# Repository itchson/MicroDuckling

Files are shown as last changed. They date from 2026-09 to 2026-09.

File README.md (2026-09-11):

<p align="center">
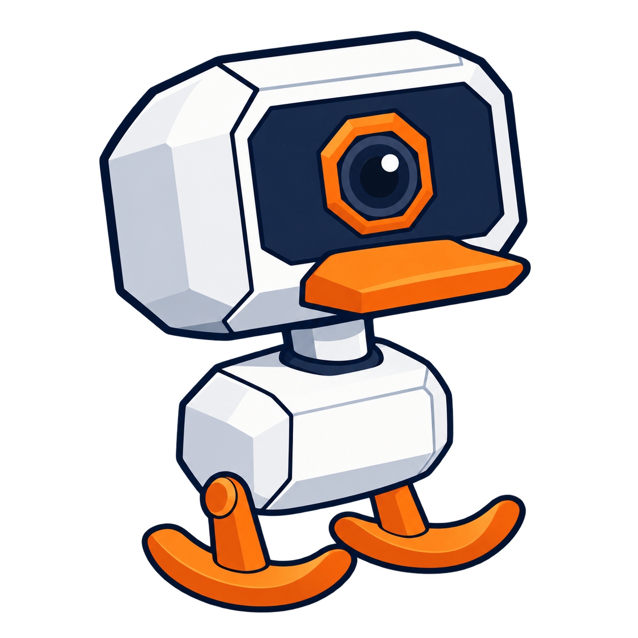
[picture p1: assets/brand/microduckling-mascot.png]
MicroDuckling: a white robot duck with a single camera and orange curved feet
  
</p>

<h1 align="center">MicroDuckling</h1>
<p align="center">A little robot to print, build, learn from and improve together.</p>
<p align="center">
  
  
  
</p>

MicroDuckling is an independent hobby robot project inspired by [Microduck from Pollen Robotics / Hugging Face](https://pollen-robotics.com/microduck/). The goal is a **small, affordable robot that people can build with printed parts and accessible electronics**, then make better as a community.

The design pairs a big faceted head and a small white body with smooth orange rocker feet. Four MG90S servos move the left leg, right leg, neck and mouth. A separate upper-mouth base mounts beneath the front of the head hood, while the lower jaw opens. The face panel is independent of the upper mouth. Printed-part assembly connections use M2 fasteners. Integrated sockets in the legs, neck carrier and jaw engage the servo output splines directly; their provisional profile still needs qualification against the actual servo batch. A local browser experiment runs rigid-body physics, searches gait patterns and approaches camera-visible targets. **NVIDIA Isaac Sim / Isaac Lab** and useful movements on real hardware remain development goals.

**This is an early CAD prototype, not a proven walking kit.** Contributions that uncover a fit problem, reduce cost, simplify assembly or improve the simulation are part of the project’s purpose.

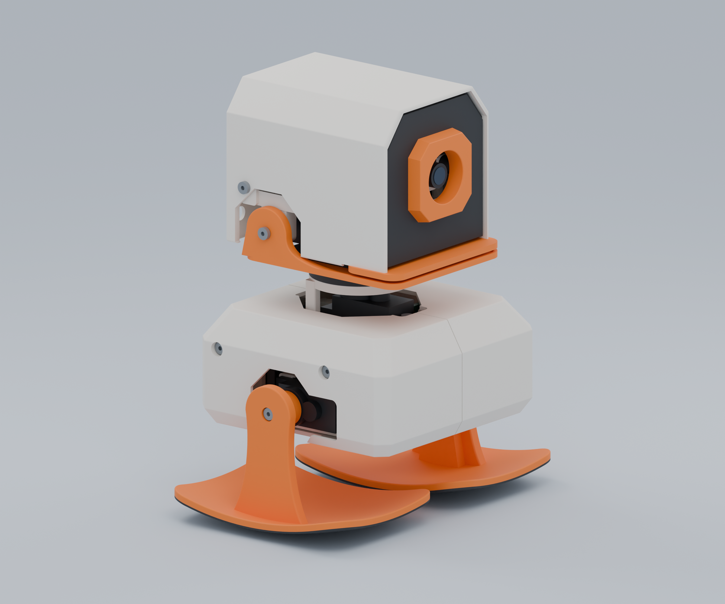
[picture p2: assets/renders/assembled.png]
R08 mechanical design and electronics visuals, assembled three-quarter view

<p align="center"><em>R08 mechanical design with separately licensed electronics visuals. The mascot is an illustration; neither image is a photograph of a working robot.</em></p>

## Where it stands

| Area | Current state |
| --- | --- |
| Mechanical design | R08: 15 robot print parts, two fit coupons, shell-mounted upper-mouth base and integrated direct servo sockets |
| Size and mass | About 136 mm tall; 250 g estimated complete mass, not measured |
| CAD checks | Printable mesh checks and sampled clearance reviews completed on the source design |
| Physical assembly | Not yet verified with printed parts and the specified hardware |
| Electronics and firmware | Four direct ESP32-CAM PWM signals and one shared 5 V regulator; I/O source and wiring supplied, hardware application/testing unfinished |
| Walking | Browser contact-model experiments; physical walking, servo temperature and traction need bench tests |
| Simulation | Physical gait search and geometric-camera approach checks tied to each asset revision; Isaac Lab scaffold remains unexecuted |
| Affordability | Proposed build with budget regulator: about A$100–110 including battery and print material; alternative mounts and power testing required |

Australian prices checked on 11 September 2026. The budget alternative uses different boards from the current CAD reference and excludes shipping, charger and tools. See [parts and costs](docs/parts-research.md), the [BOM](docs/bom.md) and the [engineering review](docs/engineering-review.md).

## Start exploring

- **Inspect the design:** open [the mechanical FreeCAD model](cad/MicroDuckling_R05_mechanical.FCStd) or [the printed-part STEP](cad/MicroDuckling_R05_printed.step).
- **Browse print files:** [STL](cad/stl/) and [3MF](cad/3mf/). Start with the clearance and spline fit coupons and the [hardware measurement checklist](docs/hardware-measurements.md); a full print is not yet qualified.
- **Understand the assembly:** read the [assembly review](docs/design-and-assembly.md) and [R08 changes](docs/r08-upper-mouth-design.md).
- **Work on simulation:** start with the [simulation guide](docs/simulation.md) and [roadmap](ROADMAP.md).

The viewer includes **82 assembly records plus two fit coupons**: 80 mechanical records and two separately supplied component visuals. R08 retains direct servo sockets without horn arms; its upper-mouth base mounts to the head shell using M2 fasteners. The IMU adapts an Adafruit PCB under CC BY-SA 3.0; the shared regulator is an original approximation. The PCA9685 and second regulator were removed. Native mechanical CAD and printed-part STEP stay separate, while mass accounts for the complete intended robot. See [license scope](docs/licensing.md) and [direct wiring](docs/electronics.md).

### Run the CAD viewer locally

Install Node.js 22.18 or newer (Node 24 is used in CI), then:

```sh
git clone https://github.com/itchson/MicroDuckling.git
cd MicroDuckling/viewer
npm ci
npm run dev
```

Open the local address printed in the terminal, normally `http://127.0.0.1:5192`. Orbit the model, select and isolate parts, open the exploded view, inspect the inside and pose the four joints. Separate browser physics controls run a gravity/contact experiment, search bounded gait parameters and test camera control using a synthetic 96 × 72 image. Joint sliders alone are a pose preview; none of these controls command hardware. FreeCAD is not required to use the viewer. See the [simulation guide](docs/simulation.md) for test coverage and the measured simulation criteria and remaining hardware limitations.

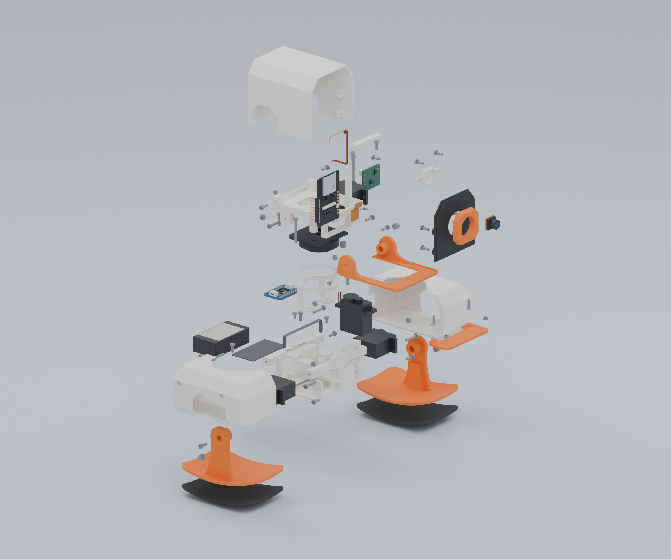
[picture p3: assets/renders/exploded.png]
Exploded view of MicroDuckling with the ESP32-CAM, IMU and single regulator


### Develop the design

The [developer guide](docs/development.md) covers the CAD toolchain, optional supplier reference downloads and checks. Parametric Python source lives in [src](src/); the native public model contains editable solids. The source is the place to change design parameters and regenerate geometry.

```sh
python -m pip install -r requirements-dev.txt
python scripts/validate_repository.py
python -m unittest discover -s simulation/tests
cd viewer
npm ci
npm test
npm run build
```

## Help a little duckling grow

You do not need to solve the whole robot to contribute. A measured servo spline, a clearly photographed fit failure, a cheaper power option, a better assembly step or a reproducible simulation result can all help.

Read [CONTRIBUTING](CONTRIBUTING.md), browse the [roadmap](ROADMAP.md), or [open an issue](https://github.com/itchson/MicroDuckling/issues/new/choose). Please include what you actually tested and distinguish measured results from estimates. The [conduct](CODE_OF_CONDUCT.md) and [governance](GOVERNANCE.md) documents explain how we work together.

## License and inspiration

Original MicroDuckling source, documentation, mechanical exports and independently authored regulator visuals use [Apache-2.0](LICENSE). The Adafruit IMU adaptation and electronics-inclusive presentation renders/thumbnails use **CC BY-SA 3.0**, with credit to Limor Fried/Ladyada for Adafruit Industries and MicroDuckling contributors. Notices for the former PCA9685 adaptation remain for historical releases. Adapted shadcn UI files retain MIT notices. See [license scope](docs/licensing.md) and [third-party notices](THIRD_PARTY_NOTICES.md) before redistributing assets.

MicroDuckling is an independent fan project, with its own design and identity. It is not an official Microduck model, a scaled copy of the official CAD, or affiliated with or endorsed by Hugging Face, Pollen Robotics or NVIDIA. Their names identify inspiration and intended tooling. The original mascot was made with OpenAI image generation; its [prompt and provenance](assets/brand/PROVENANCE.md) are included.

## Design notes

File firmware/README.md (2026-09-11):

# Direct servo I/O component

This ESP-IDF component implements the [direct-GPIO wiring plan](../docs/electronics.md): four servo signals, an OV2640 camera configuration, and a separate IMU I²C bus. It is a bring-up component, not a complete robot application or a tested hardware walking policy.

Use classic ESP32, ESP-IDF 5.4/5.5, and pinned `espressif/esp32-camera` 2.1.6. Add `components/microduckling_io` to an ESP-IDF application's components and merge `sdkconfig.defaults`, then inspect the resulting menuconfig. There is no top-level `app_main` here. GPIO16/17 stay assigned to PSRAM; microSD is unused. The component deliberately refuses a build with the wrong chip, camera I²C bus, or UART console settings.

The four servo functions require explicit measured calibration; no generic microseconds-to-angle mapping is represented as valid for the assembled robot. `md_servos_init(calibration)` starts at zero duty, with no servo pulses. `md_servos_write(angles)` accepts radians in left hip, right hip, neck, jaw order and rejects angles outside ±12°, ±12°, ±45°, and 0..12°. The 500–2500 µs outer software envelope only rejects obviously invalid calibration data; it is not an assertion that a particular servo or mechanism permits that entire range. Use smaller measured pulse bounds.

Call the servo API from one control task. Call `md_servos_stop()` on a control timeout or fault and provide a physical servo-power disconnect. LEDC can continue its last pulse train while the application is stuck; stopping PWM also does not guarantee that every servo batch releases torque. Fault detection, watchdog policy, power switching, sensing, networking, and walking control remain application work.

Duty writes use `ledc_set_duty()` followed by `ledc_update_duty()`, with both errors checked. This single-task component does not install the LEDC fade service required by ESP-IDF's combined `ledc_set_duty_and_update()` helper. Other tasks must not change its channels or start a fade on them. The [ESP-IDF 5.5.2 implementation](https://github.com/espressif/esp-idf/blob/v5.5.2/components/esp_driver_ledc/src/ledc.c) defines that service requirement.

Initialize the camera with the value from `md_camera_config()`. `md_imu_bus_init(&bus)` creates the new-driver I²C1 bus on SDA3/SCL1 with external 3.3 V pull-ups; attach the selected sensor driver at 100 kHz initially. Camera SCCB uses I²C0. Do not install the legacy I²C driver alongside the new driver. UART programming requires opening both IMU signal links; runtime UART logs are disabled.

Run `sh firmware/tests/run-host.sh` from the repository root on Linux to check pin/timer separation, command bounds, pulse conversion, and error handling. The [host-test instructions](tests/README.md) also cover Windows through WSL and explain the original test doubles. No ESP-IDF target build or board test has been completed in this environment, which has no installed ESP-IDF toolchain. Scope the 50 Hz pulses and 20 MHz camera clock together, verify camera/PSRAM/IMU operation, and qualify reset and loaded power behavior before connecting installed servo horns.

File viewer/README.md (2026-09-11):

# Local CAD viewer and physics experiment

Run from this directory with Node.js 22.18+ (CI uses Node 24):

```sh
npm ci
npm run dev
```

The terminal prints the local address, normally `http://127.0.0.1:5192`. A WebGL-capable browser is required. FreeCAD, supplier downloads, accounts and cloud services are not required.

The viewer combines 87 mechanical assembly records with four separately licensed electronics visuals; two fit coupons are also available. The parts hierarchy starts collapsed. Orbit, isolation, inside view, an assembly/explosion slider and joint sliders inspect the design. At 100% explosion, conservative mesh bounds have a gap between every component; intermediate positions are an illustration, not a collision-free removal path.

The Simulation tab runs Rapier rigid-body physics and a seeded cross-entropy search over bounded gait parameters. Its synthetic head camera renders 96 × 72 pixels, detects a magenta target and supplies only bearing/area observations to a controller. Camera learning tests bounded controller settings against visibility, centering, apparent-area growth and fall scores. It does not recognize arbitrary objects or connect to an ESP32 camera. Body travel comes from simulation, and none of these controls command hardware. See the [simulation guide](../docs/simulation.md) for assumptions and measured limitations.

`npm run prepare:cad` stages explicitly permitted CAD, component, asset and documentation files into ignored `public/`. Development, tests and builds run this step automatically. Full local engineering builds can contain Pololu STEP-derived geometry that is not approved for publication; retain the explicit staging allowlist.

```sh
npm test
npm run build
npm run preview
```

The automated checks cover geometry transforms, materials, visibility, explosion separation, the headless physics engine, image detection and the actual worker's pose/reset/learning protocol. A separate geometry raycast checks the assembled camera sightline; interactive WebGL rendering still needs browser review. Passing tests does not establish physical walking, actual servo performance or an Isaac runtime result. The displayed mass is the complete intended physical estimate; adding electronics visuals does not add their mass again.

The two Adafruit PCB mesh adaptations retain CC BY-SA 3.0; original mechanical meshes and regulator approximations use Apache-2.0. Adapted shadcn UI primitives retain MIT notices, and installed dependencies retain their licenses, including Apache-2.0 for Rapier. See [third-party notices](../THIRD_PARTY_NOTICES.md).

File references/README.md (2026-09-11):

# Component reference inputs

The public repository contains source URLs and hashes, not vendor CAD or product documentation. [inputs.json](inputs.json) records the four files required by `src/hardware_r02.py` and their original upstream notices.

From the repository root:

```sh
python scripts/fetch_reference_inputs.py --list
python scripts/fetch_reference_inputs.py
python scripts/fetch_reference_inputs.py --verify
```

Downloads go to `references/components_r02/`, which is ignored by Git. Existing files must match their recorded SHA-256 and byte count; mismatches stop the command without replacing the file. A changed upstream file needs an explicit source review and manifest update. `--verify` uses no network.

Adafruit board sources use the hardware README's CC-BY-SA 3.0 terms. The LSM6DS3 repository also supplies an MIT license file, which is fetched alongside its hardware notices. Pololu's STEP resources are manufacturer references; this project does not claim a license to redistribute them or their exact geometry. See [licensing](../docs/licensing.md).

The ESP32-CAM model uses published nominal dimensions and explicitly approximate component envelopes; it does not load a datasheet or a vendor mesh. References for dimensional facts and component selection are in the [BOM](../docs/bom.md).

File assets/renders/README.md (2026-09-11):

# MicroDuckling assembly renders

`assembled.png` and `exploded.png` show the complete 82-part R08 assembly at neutral joints. The two separate fit coupons are excluded. The exploded image uses the viewer's 100% layout, evaluated directly from `viewer/lib/explode.ts`; this is an explanatory layout, not a physical disassembly sequence. The renderer preserves every input mesh vertex and triangle and moves parts rigidly for the exploded view.

Both PNG images are licensed under **Creative Commons Attribution-ShareAlike 3.0 Unported (CC-BY-SA-3.0)**. See the [full license](LICENSE-CC-BY-SA-3.0.txt) and [license summary](https://creativecommons.org/licenses/by-sa/3.0/).

Rendered by **MicroDuckling contributors**. These images incorporate colored 3D adaptations of the following board designs by **Limor Fried/Ladyada for Adafruit Industries**:

- [Adafruit LSM6DS3TR-C 6-DoF Accel + Gyro IMU - STEMMA QT / Qwiic PCB](https://github.com/adafruit/Adafruit-LSM6DS3TR-C-PCB), represented by the `IMU` mesh.

Changes from the original Adafruit designs: PCB outlines, holes, pads and package placements were adapted from Eagle into colored 3D geometry; generic component heights and fitted connectors were added; the resulting meshes were placed and rendered in the MicroDuckling assembly. Attribution, original upstream READMEs and licenses are retained in the [component notices](../../components/README.md) and [machine-readable notice manifest](../../components/NOTICE.json).

The shared Pololu regulator visual is an original dimension-based approximation with generic component details. It is identified in the component manifest and use no manufacturer STEP geometry. The assembly and hardware remain engineering prototypes; rendered visual detail does not establish physical fit or operating performance. Product names identify represented hardware and do not imply endorsement.

`render_provenance.json` records all 82 input mesh hashes and their individual source paths, source manifest hashes, the viewer layout source hashes, the exact exploded translations, image settings and licensing. The separate mechanical CAD files retain their own license.

To reproduce after installing the viewer dependencies:

```powershell
& $blenderExe --background --factory-startup --python-exit-code 1 --python scripts/render_public_cad.py -- --width 2400 --height 2000
```

Pass `--node` followed by a Node 22.18+ executable if Node is not on `PATH`; `--device cpu` requests CPU rendering. The default selects OptiX when available and records the actual device type.

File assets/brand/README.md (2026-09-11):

# MicroDuckling identity

The mascot is an original AI-generated illustration based on the project’s white faceted head, single camera and orange rocker feet. It is branding, not an engineering drawing. The CAD renders show the actual prototype.

Use `microduckling-mascot.png` with its transparent background and space around the outline. Keep the single camera, proportions and orange accents recognizable. The project name is **MicroDuckling**; “Microduck fan project” describes the inspiration.

The asset is included under the project’s Apache-2.0 terms to the extent copyright applies. No Hugging Face, Pollen Robotics or NVIDIA logo is included. Do not imply their endorsement. See [generation provenance and exact prompt](PROVENANCE.md).

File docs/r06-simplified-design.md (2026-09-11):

# R06: upper bill and simpler electronics

Historical revision. R07 replaces the separate upper bill with an integral face feature and replaces horn attachments with direct spline sockets. See [R08 changes](r08-upper-mouth-design.md) for the current build. The dimensions, part counts and simulation evidence below describe R06 only.

R06 adds a fixed upper bill and adopts direct ESP32-CAM servo signals with one shared 5 V regulator. The robot still has four MG90S joints. The PCA9685, its four screws, its front frame/posts and the separate logic regulator cradle have been removed. The battery and IMU stay low in the body; the ESP32-CAM, flex camera and mouth servo stay in the head.

## Upper bill

The orange plate is a separate printable part, 50 mm wide, projecting from X = 30.2 to 40 mm, with a 2.2 mm flat section. Two locating keys register it against the face, with 0.15 mm nominal clearance. Two front-access M2×8 screws engage captive rear M2 nuts. The modified face has the matching slots and reinforced nut pockets.

Install the nuts and upper bill while the face/hood module is accessible, before closing the head. The lower jaw retains its driven cheek and passive pivot. Native solid checks sampled jaw opening from 0° to 12° in 1° increments: the minimum upper-to-lower bill clearance is 4.10 mm closed and increases as the jaw opens. Neck yaw from −45° to +45° was checked in 15° increments for the new parts. These are nominal geometry checks, not a physical fit certificate.

## Power and control

See [electronics and GPIO allocation](electronics.md), [BOM](bom.md) and [power research](parts-research.md). One regulated supply branches to the servo power bus and the ESP32-CAM's 5 V input, with a common ground. The existing D24V50F5 remains the dimensioned regulator reference. A cheaper substitute needs its actual dimensions, mounting arrangement and load/thermal behavior checked.

The CAD harness is still an illustrative route with a mass allowance. It does not model every signal branch, connector, capacitor, fuse or strain-relief detail. Direct PWM source is an integration component; the complete hardware application and powered tests remain unfinished.

## Direct spline experiment

The [configurable spline experiment](../experiments/spline-mount/README.md) prepares a replaceable keyed insert and small fit coupons. The supplied servo link has not established a specific spline variant. The illustrative tooth profile is not a verified MG90S interface, so the assembled model retains its existing horn attachments until that fit is established.

## Simulation and exports

The browser uses continuous tread hulls, 600 Hz integration and 16 solver iterations. Foot-load estimates, slip, loaded contact markers and the centre of mass are visible. Camera training evaluates actual travel and a stable stopping zone; looking at the target alone earns no approach reward. See [the simulation guide](simulation.md) for evidence and limitations.

There are 15 robot print parts plus two assembly fit coupons, 88 assembled mechanical records and two separately licensed component visuals. Stable `MicroDuckling_R05_*` download filenames are retained for existing links; the R06 manifest and source parameters identify that historical revision.

The complete nominal mass is **247.96 g**, with global COM **(−0.67, 0.76, 58.19) mm**. The [frozen CAD review](validation/r06-cad.json) records source/export hashes and check counts. The [six camera-approach traces](validation/r06-camera-approach.json) use the R06 mass/inertia and R06 CAD camera meshes: all six reach the stopping zone in 7.77–9.47 simulated seconds, with no falls. These are model results, not hardware measurements.

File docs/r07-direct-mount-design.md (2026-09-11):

# R07: direct servo sockets and a one-piece face

Historical revision. [R08](r08-upper-mouth-design.md) retains the direct servo sockets but replaces the fused face/upper bill with a separate upper-mouth base mounted to the head hood. The counts, clearances, assembly paths and simulation results below describe R07 only.

R07 removes all four servo horn arms from the assembled robot. Female spline sockets are built into `LegFootLeft`, `LegFootRight`, `NeckCarrier` and `Jaw`, so each printed part engages its servo output directly. Four central retaining screws remain. The fixed upper bill is fused into `FacePanel` as one connected printable solid; the separate upper-bill part, locating keys, screws and nuts are removed.

## Direct output interfaces

The geometry is defined by the `DEFAULTS` parameter mapping and construction functions in [direct_mount_r07.py](../src/direct_mount_r07.py); edit measured values there and regenerate the complete model and fit coupon together. Its default profile is an **unverified manufacturing hypothesis**, not a measured interface for every servo sold as MG90S:

| Parameter | Provisional value |
| --- | --- |
| Teeth | 20 |
| Shaft major / root diameter | 4.80 / 4.30 mm |
| Radial socket allowance | 0.06 mm |
| Socket depth | 3.80 mm |
| Nominal shaft/socket axial overlap / tip room | 3.50 / 0.30 mm |
| Nominal hub-to-crown axial gap | 0.50 mm |
| Entry lead-in | 0.35 mm |
| Full-profile overlap after the lead-in | About 3.15 mm |
| Center screw passage | 2.30 mm diameter |
| Screw-head recess | 4.50 mm diameter |

The actual assembly now uses these sockets, rather than deferring the change to an optional coupon. The four servo output shafts are separate hardware records with the corresponding toothed profile. Each belongs to its driven link and rotates with the fitted leg, neck carrier or jaw; the servo case stays on its mounting link. This nominal geometric match does not establish fit to the actual purchased shafts. The incomplete Amazon link did not identify an exact supplier variant. Tooth count, diameters, flank shape, usable shaft height, retaining-screw thread and seating stack need measurement before choosing the final values.

The socket shape is a radial trapezoidal approximation. At 20 teeth and 4.8 mm diameter, circumferential pitch is about 0.754 mm; the modeled 44% tooth-tip fraction is about 0.332 mm before allowances. That is finer than a typical 0.4 mm nozzle's extrusion width. Inspect the slicer's actual tooth paths and qualify the printed result; reducing layer height alone does not improve XY resolution. The [spline experiment](../experiments/spline-mount/README.md) retains a separate optional insert study with a different 30% tip fraction. Those experimental inserts are not extra required robot parts.

Use `SplineFitCoupon` before printing or loading a complete interface. A freely seating coupon can establish a candidate fit but cannot establish cyclic torque capacity. Check backlash, repeat assembly, tooth wear and representative loaded retention. Do not force the socket onto the output using its center screw. If printed teeth prove inadequate, a measured matching metal insert is a possible future revision.

The neck retains its support annulus and nominal 0.20 mm thrust shim. The socket transmits rotation; the seated support stack must carry head weight without preloading the servo output. The jaw retains its separate passive pivot. Mate the mouth servo and jaw before attaching the passive pivot and head frame: the checked withdrawal path moves the servo 4 mm toward negative Y to disengage the socket, then lowers it through the jaw opening; assembly reverses that path. The assembled jaw/servo module also clears the bare head frame on a sampled withdrawal path of 0.5 mm outward and then 40 mm down. Reverse that path to install the module before the passive pin and neck carrier, as described in [assembly](design-and-assembly.md). Measure central-screw engagement and blind-hole depth for each location; old horn screw lengths are not automatically correct for the new grip stacks. The schematic screw shaft lengths are 6.7 mm at each hip, 9 mm at the neck and 7 mm at the jaw. These are modeled envelopes, not qualified purchase lengths or verified screw threads.

## M2 assembly fasteners

Printed-part connections use nominal **M2 screws**, with captive M2 nuts where the existing design supplies nut pockets. The common passing clearance is 2.30 mm diameter; printed pilot holes are commonly 1.70 mm diameter (0.85 mm radius). These pilot holes are intended to be qualified with the chosen 2 mm thread-forming screw and printed material. They are not modeled internal threads, and their fit and repeated-assembly strength require representative-depth samples. The clearance coupon includes alternate passing-hole and pilot sizes for that test.

The body-shell connections retain their captive nuts. Mouth-servo mounting uses the modeled M2 nuts, and the passive jaw pivot retains its M2 locknut. Other connections use the existing printed pilots; no unmodeled nuts or inserts are assumed. Select lengths for the actual grip, head recess and available engagement, following the [hardware worksheet](hardware-measurements.md).

The **four servo-output center screws are the exception**: their actual thread must match the servo manufacturer's output shaft. Their 2 mm CAD envelope does not specify an M2 thread. This distinction does not change the M2 choice for the robot's printed-part assembly connections.

## Integral upper bill

The flat upper mouth is part of `FacePanel`, connected across the face by a fused root. It is not a separately screwed plate. The plate is nominally 50 mm wide and 2.2 mm thick, with clipped front corners that follow the faceted design. The face remains removable from the head using its existing face attachment screws; no new bill attachment hardware is needed.

A single-material face print gives the face and upper bill the same color. Painting the bill or using a suitable multicolor print is optional and does not create another mechanical part. The moving lower jaw remains a separate orange print. Nominal closed upper-to-lower bill clearance is 4.10 mm.

## Checks and simulation

The [R07 CAD record](validation/r07-cad.json) contains the native/export hashes, printable mesh round trips and detailed checks. The R07 [simulation record](validation/r07-camera-approach.json) reports 12 successful image-guided approach episodes across six target placements and two seeds. The viewer provides ground target placement, custom swing/lean/pace/phase/timing, friction and camera-search settings; see [simulation controls](simulation.md).

The revised assembly has **14 robot print parts and two coupons**, with **77 assembled records** (75 mechanical and two separate electronics visuals). Complete nominal mass is **248.66 g** and global neutral COM is **(−0.78, 0.72, 58.01) mm**. These estimates include modeled hardware and full-density plastic; they are not measurements of a printed build.

Native interface checks report zero neutral overlap between each direct socket and its matching modeled servo, with all 20 tooth crest/valley samples passing at every output. The nominal 0.06 mm radial profile allowance gives a measured CAD minimum gap of about 0.036 mm normal to the tooth flanks; radial allowance is not the same as surface-normal clearance. These compare the authored mating profiles; they do not establish hardware fit. All 15 sampled nominal assembly paths report zero collisions, including the complete jaw/servo module against the bare head frame. These isolated paths do not establish every installed-neighbor or tool-access sequence. Simulation checks must use the matching regenerated CAD, mass properties and asset hashes. Historical [R06 evidence](r06-simplified-design.md) remains available but does not establish results for R07. Nominal solid, clearance and mesh checks do not qualify the physical spline fit, tooth strength, screw retention or powered operation.

Stable `MicroDuckling_R05_*` CAD download filenames remain for existing links; the source revision and manifest identified the R07 geometry for that revision. See [assembly](design-and-assembly.md), [measurement worksheet](hardware-measurements.md), [simulation](simulation.md) and the unchanged [direct PWM/shared supply wiring](electronics.md).

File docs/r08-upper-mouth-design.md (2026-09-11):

# R08: an upper mouth mounted beneath the head hood

R08 introduces `UpperMouthBase`, a separate printable upper mouth that mounts beneath the front of `HeadHood` with M2 fasteners. Its lip follows the lower jaw. The upper mouth is no longer fused to `FacePanel` and does not fasten to it; the face remains an independent removable part.

The four direct servo sockets, rotating output-shaft records, neck thrust support and passive jaw pivot remain. Their default 20T/4.80 mm major/4.30 mm root spline profile is still unverified against the actual servo batch. Use the spline fit coupon and [hardware worksheet](hardware-measurements.md) before accepting physical fit or load capacity. The [R07 record](r07-direct-mount-design.md) documents the introduction and parameters of these retained interfaces.

The part and shell mounts are authored in [upper_mouth_r08.py](../src/upper_mouth_r08.py). Regenerate the hood and upper-mouth base together after changing their interface parameters.

## Geometry and shell mounting

| Feature | Nominal CAD value |
| --- | --- |
| Upper lip front / width | X = 36 mm / 54 mm, aligned with the lower jaw |
| Plate thickness and vertical extent | 2 mm, Z = 82.9–84.9 mm |
| Closed upper-to-lower lip gap | 1.0 mm |
| Upper-mouth base to face clearance | 0.8 mm |
| Two locating-register centers | X = 18 mm, Y = ±22 mm |
| Register radius / height | 2.6 / 1.2 mm |
| Socket radial / end allowance | 0.15 / 0.20 mm |
| Nut-bearing web above register socket | 1.2 mm |

The rear central relief clears the camera and head frame. The locating registers seat into the hood bosses and carry alignment loads. Two M2×8 countersunk screws enter from below and engage captive M2 nuts in the hood. Their modeled Ø4 mm heads use a 90° cone over 1 mm plus a 0.2 mm rim, with 1.3 mm hex drives and matching recessed seats. The heads sit flush with the upper-mouth underside. Both countersunk seats have nominal cone contact, and straight 1.3 mm across-flats hex-driver access was checked from below against the loose hood, base and screws. That access check excludes the jaw, face, electronics and body, so complete the fastening before those parts obstruct the tool. These are modeled screw envelopes; delivered head and nut dimensions need checking.

## Assembly

Load the two M2 nuts through the open front of the loose hood **before fitting the face panel or electronics**. The sampled withdrawal route lifts each nut 3 mm, moves it 8 mm toward the center and then 30 mm forward; reverse that route to load the pockets. Seat the upper-mouth base on its registers and tighten the two screws while the jaw is absent and the underside is accessible. Fit the independent face panel afterwards. The upper-mouth base stays attached to the hood when the face is removed. With its screws removed, the base has a sampled 0–40 mm straight downward withdrawal path from the loose hood and independently from the face; these checks exclude the jaw and populated internal assembly.

Printed-part connections retain nominal M2 fasteners; vendor-specific servo center screws must match the actual output threads. See [assembly](design-and-assembly.md) for the retained jaw/servo sequence and [fastener measurements](hardware-measurements.md) for pilot and grip qualification.

## Fastener reference

The countersunk mounting geometry uses a 90° head reference. [Bossard's countersunk screw description](https://www.bossard.com/au-en/eshop/screws-and-bolts-with-internal-drive/hex-socket-flat-countersunk-head-screws-fully-threaded/p/2105/) identifies that included angle. Its [supplier dimensional sheet](https://xonstorage.z8.web.core.windows.net/pdf/bossard_1021729_sup11manufacturerlinknew.pdf) lists an M2 variant with maximum 4 mm head diameter, 1.2 mm head height and a 1.3 mm hex drive. The sheet also says M2 is not included in DIN 7991, so these are supplier-reference dimensions, not a universal M2 head specification. Check the delivered screw head, drive access, nut fit and printed countersink before assembly.

## Validation scope

The assembly contains **15 robot print parts and two fit coupons**, with **82 assembled records** (80 mechanical and two separately supplied electronics visuals). Complete nominal mass is **250.34 g**, with global neutral COM **(−0.66, 0.72, 58.18) mm**. These are CAD estimates, not measured build values.

Jaw clearance was sampled every 1° through 0–12° opening: the minimum upper-to-lower mouth gap is **1.0 mm** at closure and increases to approximately **7.74 mm** at the open limit. The [R08 CAD record](validation/r08-cad.json) identifies the frozen native model and exported geometry. All native solids are valid, 19 sampled insertion paths report no collisions, and the sampled joint-motion and combined jaw/neck checks report no interference. Static review contains 37 nominal material engagements; the two new pairs are upper-mouth screw/nut thread contacts. Direct-socket, mouth, driver-access, harness and display checks pass. These checks are scoped to the modeled parts and sampled paths.

The [R08 camera-approach record](validation/r08-camera-approach.json) reports **12 successful episodes with no falls**, covering six target placements and reset seeds 2026 and 42, including an initially out-of-view target. Completion took **8.55–46.77 simulated seconds**. The evaluator verifies source and canonical/cached mesh hashes before testing the CAD-occluded synthetic camera. The 62 viewer/simulation tests, TypeScript/Vite build and 27 Python tests also pass. These finite cases do not establish success for every placement, custom gait, surface or load.

R07 geometry and learning traces remain historical, and training was not rerun for R08. Geometric clearances do not establish printed fit, fastener retention, spline wear, power stability or physical walking. NVIDIA Isaac Sim / Isaac Lab runtime and hardware transfer remain development work.

The [shared 5 V supply and direct ESP32-CAM signals](electronics.md), [parts budget](bom.md) and component-license boundaries are unchanged. Stable `MicroDuckling_R05_*` download filenames remain for existing links; inspect the manifest revision for the actual design.

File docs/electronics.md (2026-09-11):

# Direct servo wiring

The current electrical plan removes the PCA9685. The ESP32-CAM generates four servo control signals, and one regulated **5 V supply** powers the camera board and all four MG90S servos. Keep the body-mounted six-axis IMU. This is a concrete wiring and firmware bring-up plan; simultaneous camera, servo, reset and power behavior still need bench qualification.

This allocation is for the **classic Ai-Thinker ESP32-CAM with OV2640 and PSRAM**, using the exposed headers, with microSD empty and disabled. Other boards sold as “ESP32 camera” need their own schematic check.

## Signal connections

| Function | ESP32-CAM header | Connection |
| --- | --- | --- |
| Left hip servo signal | IO2 | High-speed LEDC channel 0 |
| Right hip servo signal | IO13 | High-speed LEDC channel 1 |
| Neck yaw servo signal | IO14 | High-speed LEDC channel 2 |
| Jaw servo signal | IO15 | High-speed LEDC channel 3 |
| IMU SDA | U0R / GPIO3 | Through removable signal link J1 |
| IMU SCL | U0T / GPIO1 | Through removable signal link J2 |
| IMU VIN | 3V3 | For the selected Adafruit LSM6DS3TR-C breakout |
| IMU and servo grounds | GND | Common with regulator and camera board |
| All four servo positive leads | Shared 5 V bus | Do not route motor current through a GPIO or the ESP32-CAM PCB |
| ESP32-CAM supply | 5V | Separate branch from the same regulator |

The [Ai-Thinker schematic](https://docs.ai-thinker.com/_media/esp32/docs/esp32_cam_sch.pdf) shows these GPIOs on the headers and microSD wiring. GPIO4 also controls the onboard white flash LED, so this allocation leaves it unused. GPIO16 is connected to **PSRAM chip select**, and GPIO17 to its clock; neither is a spare servo or IMU pin. GPIO12 stays unused because its reset level selects the flash supply voltage. The [ESP32 GPIO documentation](https://docs.espressif.com/projects/esp-idf/en/v5.5.2/esp32/api-reference/peripherals/gpio.html) identifies these peripheral and reset restrictions.

Add a **10 kΩ pull-down to ground on GPIO2 and GPIO15**, near the ESP32-CAM. These are proposed external bias values to verify on the actual board, including its microSD pull-ups. Check both reset levels with the chosen servo batch connected. Servo signal inputs must tolerate 3.3 V commands and must not drive the ESP32 pin above its supply. TowerPro's published MG90S page does not establish a universal input threshold for all units sold under that name; verify the purchased batch. A signal buffer may be necessary if it fails that check, without adding a separate PWM controller.

## Reset and programming

GPIO2 must be low or floating for UART download when GPIO0 is held low; normal flash boot ignores GPIO2. GPIO15 low suppresses ROM boot messages on GPIO1, which becomes IMU SCL. GPIO12 high at reset can select a 1.8 V flash supply and prevent a 3.3 V board from booting; this plan never connects a peripheral to it. These behaviors are documented in [Espressif's boot-mode guide](https://docs.espressif.com/projects/esptool/en/latest/esp32/advanced-topics/boot-mode-selection.html) and the [ESP32 datasheet, boot configuration tables](https://www.espressif.com/sites/default/files/documentation/esp32_datasheet_en.pdf).

Use two removable links, one for each IMU signal. For programming:

1. Turn off robot power and isolate the servo 5 V branch. Open J1 and J2 so the programmer cannot contend with the IMU.
2. Connect a **3.3 V logic** USB-UART adapter: adapter TX → U0R/GPIO3, adapter RX → U0T/GPIO1, and common ground. Keep one intended 5 V source; do not parallel the adapter's power output with the regulator.
3. Hold GPIO0 to ground while resetting or powering the ESP32-CAM into download mode. GPIO2 must remain low. Flash the application.
4. Power off, remove the GPIO0-to-ground link and programmer signal leads, then close J1/J2. Restart with servo power still isolated and check camera/IMU initialization before enabling the servo branch.

Runtime UART logging and console input are unavailable with the IMU connected. Set `CONFIG_ESP_CONSOLE_NONE=y` and `CONFIG_BOOTLOADER_LOG_LEVEL_NONE=y`; do not add later `Serial`, UART, console or panic-output configuration that drives GPIO1/3. GPIO15's pull-down addresses the earlier ROM output that firmware settings cannot suppress. [ESP-IDF console configuration](https://docs.espressif.com/projects/esp-idf/en/v5.5.2/esp32/api-reference/kconfig.html#config-esp-console-uart) describes this distinction. A USB programmer base must also be electrically disconnected from the reused pins during normal operation.

## Camera, PWM and I²C allocation

The existing camera signals stay unchanged: XCLK0; SCCB SDA26/SCL27; D0–D7 on 5/18/19/21/36/39/34/35; VSYNC25, HREF23, PCLK22, PWDN32, no reset GPIO. This matches [Espressif's Ai-Thinker camera pin map](https://github.com/espressif/arduino-esp32/blob/master/libraries/ESP32/examples/Camera/CameraWebServer/camera_pins.h).

Use **ESP-IDF 5.4/5.5**, with `esp32-camera` **2.1.6** pinned for this bring-up component:

| Peripheral | Explicit resource |
| --- | --- |
| Camera XCLK | Low-speed LEDC timer 0, channel 0; 20 MHz |
| Four servos | High-speed LEDC timer 0, channels 0–3; 50 Hz, 16-bit duty |
| Camera SCCB | I²C controller 0 on GPIO26/27 |
| Body IMU | I²C controller 1 on GPIO3/1; start at 100 kHz |

The two LEDC banks are independent on classic ESP32. Espressif's pinned [camera clock implementation](https://github.com/espressif/esp32-camera/blob/v2.1.6/target/xclk.c) explicitly selects `LEDC_LOW_SPEED_MODE`; the servo component explicitly selects `LEDC_HIGH_SPEED_MODE`. Do not let an automatic Arduino PWM allocator reassign the camera timer. [LEDC documentation](https://docs.espressif.com/projects/esp-idf/en/v5.5.2/esp32/api-reference/peripherals/ledc.html) describes the separate modes and timer/channel configuration.

**Camera SCCB defaults to I²C1 in this camera release.** Override it with `CONFIG_SCCB_HARDWARE_I2C_PORT0=y`; merely changing IMU pins would leave a bus conflict. Select `CONFIG_SCCB_HARDWARE_I2C_DRIVER_NEW=y` and use the new I²C API for the IMU too. The camera's [Kconfig](https://github.com/espressif/esp32-camera/blob/v2.1.6/Kconfig) and [build selection](https://github.com/espressif/esp32-camera/blob/v2.1.6/CMakeLists.txt) establish these defaults and the IDF 5.4 driver transition.

For the selected Adafruit board, use 3.3 V at VIN and retain its I²C pull-ups to that logic supply. Do not pull the ESP32 signals to 5 V. The [Adafruit pinout](https://learn.adafruit.com/adafruit-lsm6ds3tr-c-6-dof-accel-gyro-imu/pinouts) gives the default address, power and pull-up details. Poll the sensor initially; no extra interrupt GPIO is allocated. A different IMU breakout needs its own power, address and driver check. Manual supported poses can omit the IMU, but the planned balance policy requires angular velocity and gravity-direction observations.

## One shared 5 V supply

```text
2S battery → switch/protection → one 5 V buck regulator
                               ├─ servo power bus → four servo + leads
                               └─ separate camera branch → ESP32-CAM 5V
ESP32-CAM 3V3 → IMU VIN
All returns → common ground, with short separate servo/camera power paths
```

The existing regulator candidate, current assumptions and decoupling proposal are in the [BOM](bom.md) and [power research](parts-research.md). A second external logic regulator is not required by this plan. The ESP32-CAM still uses its onboard 3.3 V regulator. Keep servo return current out of the camera's ground wiring, and measure voltage at both branch endpoints during simultaneous servo loading and Wi-Fi capture. A larger capacitor does not establish current capacity or guarantee brownout-free operation.

## Bring-up status

The [firmware I/O component](../firmware/README.md) supplies explicit pin/timer setup, zero-duty startup, calibrated angle-to-pulse conversion and limits. It requires measured servo direction, neutral and pulse limits; there is no generic calibration or automatic walking application.

Before installed motion, verify reset/download behavior, all four 50 Hz signals alongside camera XCLK, PSRAM frame capture, IMU reads, and servo input voltage. Then test a supported robot with constrained motion, measure loaded 5 V transients and regulator temperature, and exercise command timeout, reset and physical servo-power isolation. These checks remain outstanding on hardware. Removing the PCA9685 does not by itself make a stalled program safe: the ESP32 LEDC hardware can keep producing its last commanded pulses.

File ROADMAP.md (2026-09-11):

# Roadmap

The aim is a small, affordable hobby robot that is easy to build and rewarding to improve. MicroDuckling is inspired by Hugging Face / Pollen Robotics' Microduck. The longer-term direction is to train locomotion in NVIDIA Isaac Sim and evaluate it on physical hardware.

This is a sequence of learning and validation stages, not a schedule. Work can overlap, and measurements may require changes to earlier designs. Contributions that reduce cost, simplify assembly or make results easier to reproduce are welcome throughout.

## Current baseline: R08 design prototype

- Four MG90S joints, 15 robot print parts with direct spline sockets and a separate shell-mounted upper-mouth base, plus two fit coupons.
- Approximately 250 g complete mass is derived from the current CAD; this is not a measured build weight.
- CAD, mesh, sampled motion and assembly-access checks, plus a static simulation scaffold and tests.
- A local browser physics experiment, bounded gait search and synthetic-camera controller experiments; each geometry revision needs matching model-based gait and camera-approach checks; physical transfer remains unproven.
- No qualified physical assembly, completed firmware, Isaac Sim runtime or training result, or demonstrated physical walking.

The [engineering review](docs/engineering-review.md) and [R08 notes](docs/r08-upper-mouth-design.md) describe the current checks and exclusions. The following stages describe work still needed.

## 1. Measure the actual hardware

Record dimensions and masses for the actual servos, output splines, seated direct sockets, screws, electronics, connectors and battery. Resolve differences between purchased parts, manufacturer references and CAD assumptions. Keep part identity and measuring method with each result.

**Useful outcome:** a completed [measurement worksheet](docs/hardware-measurements.md), a list of discrepancies and CAD updates supported by those measurements.

**Ways to help:** mechanical inspection, component sourcing, measurement photos and clearer worksheets.

## 2. Print and assemble incrementally

Start with fit coupons, then test the affected interfaces and a complete assembly. Check print orientation, fastening, tool access, wire routing, service loops, restraint and disassembly with the actual parts. Record failed fits and changes as carefully as successful ones.

**Useful outcome:** documented print settings and an assembly sequence that someone else can repeat, with remaining fit or strength questions listed and an actual build mass recorded.

**Ways to help:** printing, CAD refinement, assembly documentation and reducing part count or cost.

## 3. Establish the electrical system

Turn the proposed component arrangement into a documented wiring and power design. Resolve connector choices, battery protection and monitoring, servo power disable behavior and strain relief. Measure rail voltage, current and temperature under representative loads, including more than one servo moving.

**Useful outcome:** a reproducible wiring diagram and bench results that support the chosen components and operating limits. Geometric cable corridors alone do not establish a working harness.

**Ways to help:** electronics design, power measurements, wiring layouts and test procedures.

## 4. Bring up firmware and characterize motion

Implement and document controller setup, joint calibration, bounded position commands, rate limits, IMU axes, logging and watchdog / disable behavior. Measure servo direction, range, lag, backlash and loaded response. Establish a control and observation interface that simulation and firmware can share.

**Useful outcome:** repeatable bench bring-up with calibration and logs, including observed behavior after communication loss or reset. Use the measured behavior to replace assumptions in the simulation model.

**Ways to help:** embedded software, instrumentation, calibration tools and actuator characterization.

## 5. Run and evaluate simulation

Confirm a supported Isaac Sim / Isaac Lab setup, import the robot, inspect joints and collisions, and exercise physics before training. Compare the model with measured mass, actuator and contact behavior. Run small training experiments, then evaluate across seeds and held-out parameters with recorded configurations and metrics.

**Useful outcome:** a reproducible Isaac runtime and training workflow, with logs distinguishing import checks, diagnostic motion and learned behavior. The browser parameter search is an early experiment; there is no trained Isaac policy yet.

**Ways to help:** simulation integration, reinforcement learning, system identification and experiment documentation. Start with the [simulation notes](docs/simulation.md), including their version and runtime limitations.

## 6. Evaluate physical locomotion and simplify the build

Bring tested control or policy behavior to the robot through supported, bounded motion trials. Record falls, slip, power behavior, temperatures and performance on stated surfaces. Compare physical behavior with simulation and revise the design or model where they disagree.

**Useful outcome:** repeatable physical walking evidence with the hardware revision, calibration, controller or policy, test conditions and limitations included. Use independent build feedback to improve instructions and work toward a qualified build release.

**Ways to help:** physical testing, sim-to-real analysis, assembly feedback, accessibility and documentation.

See [CONTRIBUTING.md](CONTRIBUTING.md) to share a result or propose a change. A small, well-documented measurement can unblock several of these stages.

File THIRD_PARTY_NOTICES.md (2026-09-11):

# Third-party notices

MicroDuckling is an independent hobby project inspired by [Microduck](https://pollen-robotics.com/microduck/) from Pollen Robotics, the robotics team at Hugging Face. It is not affiliated with or endorsed by either organization. The four-servo mechanism and printed parts are specific to MicroDuckling.

The [Microduck runtime](https://github.com/pollen-robotics/microduck) and [training repository](https://github.com/pollen-robotics/microduck_rl) were studied as references. Their software is distributed under Apache-2.0. This repository does not distribute their runtime, policies or official mechanical meshes. Pollen's [press kit](https://pollen-robotics.com/microduck/press-kit/) explains the scope of its open-source release.

## Included UI components

`viewer/components/ui/button.tsx`, `viewer/components/ui/checkbox.tsx`, `viewer/components/ui/slider.tsx` and `viewer/lib/utils.ts` are adapted from [shadcn/ui](https://github.com/shadcn-ui/ui), Copyright (c) 2023 shadcn. They retain the MIT license in [licenses/shadcn-ui-MIT.txt](licenses/shadcn-ui-MIT.txt). The repository's Apache license does not replace that notice. Changes integrate the components into the MicroDuckling viewer and its styling.

React, Three.js, Base UI, Lucide, Tailwind CSS and other installed dependencies retain their respective licenses. The package manifests and lockfile identify the dependency versions; their packages supply the applicable notices.

The browser physics module uses `@dimforge/rapier3d-compat` 0.20.0, the official JavaScript/WebAssembly bindings for [Rapier](https://github.com/dimforge/rapier). The installed package and [upstream license](https://github.com/dimforge/rapier/blob/master/LICENSE) identify Apache-2.0. It is installed through npm, not copied into this repository as vendored source. Preserve applicable dependency notices when distributing built viewer bundles.

## Included electronics visuals and renders

`components/meshes/IMU.json` adapts **Adafruit LSM6DS3TR-C 6-DoF Accel + Gyro IMU - STEMMA QT / Qwiic PCB**; the historical PCA9685 adaptation was removed from the active R06 build. The original IMU design is by **Limor Fried/Ladyada for Adafruit Industries** and the IMU mesh adaptation retains **CC-BY-SA-3.0**. MicroDuckling contributors converted Eagle outlines, holes, pads and package positions to colored 3D meshes, added approximate heights and fitted connectors, and placed the boards in the assembly. These are not manufacturer mechanical CAD.

Source titles, URLs, board hashes, mesh hashes and changes are recorded in [components/NOTICE.json](components/NOTICE.json). The complete upstream notices are included without replacing their hardware-specific terms:

- [LSM6DS3TR-C README](components/licenses/adafruit-lsm6ds3/README.md), [CC hardware license](components/licenses/adafruit-lsm6ds3/license.txt), and [additional upstream MIT notice](components/licenses/adafruit-lsm6ds3/LICENSE).
- [PCA9685 README](components/licenses/adafruit-pca9685/README.md) and [CC hardware license](components/licenses/adafruit-pca9685/license.txt).

`components/meshes/Buck_0.json` is an **Apache-2.0 original visual approximation by MicroDuckling contributors** of the Pololu D24V50F5. The D24V10F5 visual was removed in R06. Published dimensions and photographs informed generic geometry. No manufacturer STEP, prior regulator mesh, photograph, drawing image, logo or silkscreen is included. Product names identify represented hardware and do not imply endorsement or a license over that hardware.

Electronics-inclusive assembled/exploded renders and their derivative thumbnails are released as composite artwork under [CC-BY-SA-3.0](https://creativecommons.org/licenses/by-sa/3.0/). Attribution: **MicroDuckling contributors — robot design, mesh adaptations and rendering; Limor Fried/Ladyada for Adafruit Industries — original IMU PCB design (historical R05 images also incorporated the PCA9685 design)**, with source details in the component notice above. Keep this attribution and license with redistributed images. See [render provenance](assets/renders/render_provenance.json) for asset inputs. The separately identified [AI-generated mascot](assets/brand/PROVENANCE.md) and independent mechanical source remain under the project's Apache-2.0 terms.

## Downloaded component references

The CAD source can load the following manufacturer files for local engineering review. The original downloaded inputs remain outside the public repository; the separately licensed Adafruit adaptations are included as described above. Pololu STEP-derived meshes remain excluded. The project's Apache license does not replace upstream terms.

| Component | Source | Terms and attribution |
|---|---|---|
| Adafruit PCA9685 product 815, rev C PCB | [Official Eagle repository](https://github.com/adafruit/Adafruit-16-Channel-PWM-Servo-Driver-PCB) | Hardware README selects CC-BY-SA 3.0; designed by Limor Fried/Ladyada for Adafruit Industries. |
| Adafruit LSM6DS3TR-C product 4503 PCB | [Official Eagle repository](https://github.com/adafruit/Adafruit-LSM6DS3TR-C-PCB) | Hardware README selects CC-BY-SA 3.0; the repository also contains an MIT license file. Both notices are fetched. |
| Pololu D24V50F5 | [Manufacturer resources](https://www.pololu.com/product/2851/resources) | Manufacturer STEP model. No redistribution permission is claimed here. |
| Pololu D24V10F5 | [Manufacturer resources](https://www.pololu.com/product/2831/resources) | Manufacturer family STEP model. No redistribution permission is claimed here. |
| Ai-Thinker ESP32-CAM | [Manufacturer datasheet mirrored by LCSC](https://datasheet.lcsc.com/lcsc/Ai-Thinker-ESP32-CAM-C277946.pdf) | Nominal dimensions inform a project-created approximate representation; the PDF and its illustrations are not distributed here. |
| ESP32-CAM pin mapping | [Espressif camera example](https://github.com/espressif/arduino-esp32/blob/master/libraries/ESP32/examples/Camera/CameraWebServer/camera_pins.h) | Reference link; the complete example header is not included. |

The [input manifest](references/inputs.json) records download URLs, SHA-256 hashes and upstream notice files. The fetch script also saves notices alongside each local input. Preserve complete upstream READMEs, licenses, creator attribution and change descriptions when redistributing the Adafruit adaptations. Their inclusion in the viewer does not change the license of the separate printed-part exports.

FreeCAD, NumPy, trimesh, Isaac Lab, Isaac Sim and their dependencies are installed separately. Isaac Lab v2.3.2 uses [BSD-3-Clause](https://github.com/isaac-sim/IsaacLab/blob/v2.3.2/LICENSE). The simulation scaffold uses its APIs and invokes its installed training scripts; it does not bundle those packages.

The offline geometric-camera tests use [three-mesh-bvh](https://github.com/gkjohnson/three-mesh-bvh), copyright 2018 Garrett Johnson, under its MIT license. It is installed as a development dependency with its upstream license; no library source is copied into this repository.

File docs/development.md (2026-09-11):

# Development

See [build and validation](build.md) for Python setup, verified component downloads, the FreeCAD rebuild and static simulation checks. [CONTRIBUTING](../CONTRIBUTING.md) describes review and contribution practices.

The active mechanical source is `src/build_cad.py` with `body_r04.py`, `head_r04.py`, `electronics_r04.py`, `hardware_r02.py`, `direct_mount_r07.py` and `upper_mouth_r08.py`. R04 module suffixes record their introduction; the current assembly is R08. Source dimensions are millimetres. Detailed vendor geometry is an optional local input; it is not part of the public CAD payload.

All local CAD/audit/simulation outputs default to `build/local/`. For a separate output location, set `MICRODUCKLING_BUILD_ROOT` before invoking any build or simulation command. Do not set it to the repository root or a published source/assets directory. The reference cache stays at `references/components_r02/`.

When dimensions or mass assumptions change, regenerate CAD, repeat the nominal geometry checks, derive new simulation assets and rerun the numerical checks. Keep numerical geometry results distinct from physical measurements or successful dynamics. See [engineering review](engineering-review.md), [hardware measurements](hardware-measurements.md), [simulation](simulation.md) and [licensing](licensing.md).

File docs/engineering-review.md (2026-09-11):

# Engineering review

**R08 is the active CAD prototype.** See [R08 changes](r08-upper-mouth-design.md) for the separate shell-mounted upper-mouth base; direct spline sockets are retained. The historical R05 evidence below does not describe the new assembly. No physical assembly, electrical load/thermal test, Isaac runtime execution or hardware gait is reported. Browser physics and policy-search experiments do not establish those results. The following summarizes the original R05 engineering checks and distinguishes them from checks of the public export.

## Original detailed CAD review

The original 2026-09-11 R05 assembly used detailed purchased-component references. Its nominal mass is 257.28 g and neutral COM is approximately (0.19, 0.57, 57.23) mm in the global CAD frame. Source CAD SHA-256: `4819acd1b9158d1ec77f48f93f5091425a44d6252d6c162664b00be08dc9bd09`. Source assembly JSON SHA-256: `68bd9fd40488ea97935b10021dbdd4c666b5d1f31ce9d6946a4177c1063c7f72`. Those hashes identify the historical R05 build. Current [assembly metadata](../cad/assembly.json) records the current source identities and publication omissions.

| Original check | Reported result and scope |
|---|---|
| Saved solids | Reopened solids valid. |
| Print/coupon exports | 16 watertight, consistently wound, positive-volume, single-component STL meshes; geometry-only 3MF round trips matched. |
| Static intersections | 47 identified screw/shaft, screw/nut or printed-pilot engagements; no unexplained pairs. |
| Independent motion | No overlaps above 0.05 mm³: hips every 2°, neck every 5°, jaw every 1°. |
| Combined jaw/neck samples | No jaw-print/body-print overlap above 0.05 mm³ at jaw every 2° and yaw every 15°. |
| Rigid insertion | 12 components clear of named bare frames; straight steps 2 mm and stepped mouth/regulator paths at most 1 mm. |
| Neutral wire routes | Three illustrative harness groups checked against rigid geometry and each other, with no unexplained overlap above 0.01 mm³. |
| Access and seam | 0.300 mm nominal body seam; an 8 × 4 mm rear cable probe; four Ø4.2 mm face-screw access envelopes on the loose hood. |

Independent motion excludes illustrative flexible harnesses and four identified servo/shaft-screw engagement pairs. A hip sweep omits the opposite leg. Combined samples cover the printed jaw against body prints only. These are discrete nominal intersection tests, not continuous sweeps, minimum-clearance guarantees, tolerance stacks or physical fit tests. The insertion checks omit neighboring installed components. The loose hood access result does not imply a screwdriver can reach those screws with the head assembled.

## Public export

The public STEP contains project-created printed parts. The native mechanical CAD and mechanical mesh collection also retain project-created hardware approximations, but exclude the four electronics visuals supplied separately under `components/`. The viewer combines **87 mechanical assembly records and four electronics records**, with two additional fit coupons. Those counts describe display records, not 93 printed parts.

The historical R05 IMU and servo-controller meshes adapted Adafruit PCB geometry under CC-BY-SA-3.0. The historical two regulator meshes were original dimension-based approximations under Apache-2.0, with photo-informed generic component arrangements; they do not use Pololu STEP geometry. [Component records](../components/records.json) preserve the original physical mass/COM estimates while describing the new display geometry; [attribution](../components/NOTICE.json) identifies the sources and changes. R06 removes the PCA9685 and second regulator; current component records contain the IMU and shared regulator only. The full intended assembly mass remains in metadata and must not be increased again when adding the visual records.

The component visuals are for identification and assembly explanation. Their approximate heights, connectors and package shapes are not qualified for fit, collision, electrical, thermal or manufacturing checks. [Public export checks](../cad/public_export_checks.json) cover the mechanical exports; restoring the electronics display does not re-prove the original full-assembly collision review. Electronics-inclusive presentation renders and thumbnails carry the separate license scope described in [licensing](licensing.md).

Regenerating local full CAD uses [separately downloaded references](../references/README.md) and writes to `build/local/`. Reports created by the [build workflow](build.md) bind their results to the actual local CAD hash. Original reported results must not be relabeled as results for an edited model.

## Before a build or gait claim

Measure the four actual servos and output splines, test representative printed pilots, verify every installed component/tool path, finish the harness and battery restraint, and measure current, voltage and temperature under simultaneous motion. Weigh completed links and qualify traction and structural strength. Then verify the Isaac import, contacts and actuator model, train and evaluate policies, and test bounded physical motion. The [hardware worksheet](hardware-measurements.md) and [simulation guide](simulation.md) define those next steps.

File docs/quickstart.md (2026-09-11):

# Start here

MicroDuckling is an engineering prototype. The public files support inspection, modification and fit experiments; they are not a tested assembly kit. Browser walking and camera approach are model experiments; a working hardware application and Isaac-trained policy are not supplied.

1. Read the [engineering review](engineering-review.md) and [R08 changes](r08-upper-mouth-design.md).
2. Inspect the printed parts in `cad/stl/`, the coupons in `cad/coupons/`, and the geometry-only files in `cad/3mf/`. The 3MF files have no printer profiles.
3. Select the exact parts in the [BOM](bom.md) and fill out the [measurement worksheet](hardware-measurements.md). Start with the coupons before printing the whole robot.
4. Follow [build and validation](build.md) to regenerate local CAD or run the numerical tests.
5. Use [simulation](simulation.md) for the planned Isaac workflow and its current limits.

All CAD dimensions are millimetres. Four MG90S servos drive left hip pitch, right hip pitch, neck yaw and the jaw. The planned controller is an ESP32-CAM using four direct GPIO servo signals, one shared 5 V regulator and a body-mounted IMU. See the [pin and power allocation](electronics.md). Battery monitoring, fault shutdown and firmware still need implementation and tests.

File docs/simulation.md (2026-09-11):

# Simulation experiments and Isaac scaffold

The viewer runs rigid-body physics, searches bounded gait parameters and tests image-guided approach. Its browser model is separate from the Isaac Lab scaffold. No Isaac runtime execution, Isaac-trained policy or physical walking result is supplied. R06 and R07 traces below are retained as historical evidence and do not certify changed R08 assets; consult the [R08 design record](r08-upper-mouth-design.md) for matching CAD and camera-approach checks. Training was not rerun for R08.

## Browser contact and weight

Five articulated rigid bodies and four revolute joints move under gravity. Continuous hulls derived from the actual tread meshes plus interior contact envelopes give nine robot colliders. The default is 600 Hz integration with 16 solver iterations. The old 109-box contact layout remains an explicit comparison option; its apparent gait speed was sensitive to timestep and is not the default. Mass, COM and inertia derive from the complete current CAD, including the independent face panel, shell-mounted upper-mouth base, direct servo sockets and simplified electronics. Collider geometry does not add mass again.

The interface shows COM, loaded contacts, slip speed, weight and estimated support. Ground friction and mass scaling restart the experiment so old scores do not describe a changed environment. Debug markers are excluded from the robot's camera image. See [contact physics and force definitions](browser-contact-physics.md): support uses momentum balance; per-foot loads use solver-impulse shares and are estimates. Tangential force is unavailable, rather than displayed as a false zero.

Self-collision is disabled because the interior envelopes are not exact outer shell shapes. The actuator model uses bounded PD effort, a 3 rad/s command slew limit, a 0.09 N·m effort ceiling and a 10.47 rad/s speed prior. Hip travel is ±12°, neck yaw ±45° and jaw opening 0–12°. These are unmeasured motor assumptions, with no thermal or electrical plant. Forward motion comes from integrated contact dynamics; no animation translates the body along a path.

## Gait search

**Step & balance** offers a custom swing, forward lean, pace, left/right phase, step timing and optional head sway. **Apply custom gait** selects those settings for playback, camera approach and the next search seed. Swing automatically shrinks as lean approaches the ±12° hip limit; commanded lean is not guaranteed body tilt. Camera tracking takes control of the neck during approach. **Restore reference** returns to the bundled gait, and **Play selected gait** runs whichever controller is selected.

Replaying the reference is not labeled new learning. **Start gait search** evaluates neutral and the selected seed, then runs up to 12 generations of 12 physical, 14-second candidate episodes. A phase-aware cross-entropy search varies frequency, bias, amplitude, duty, harmonics, phase and jaw motion. Each episode settles for one second before measurement. Search can change the custom seed settings; the sliders remain an editable draft until applied again.

The score rewards sustained late-episode COM velocity and net forward travel with lateral, heading and tilt costs. Falls are rejected. The interface reports actual episodes, speed, displacement and whether a newly searched candidate improved on the supplied seed. Parameter search in this small controller family is not a trained Isaac neural policy. Use held-out surfaces, loads and reset seeds before judging robustness.

Historical [R06 gait evidence](validation/r06-locomotion-summary.json) evaluates 12 thirty-second trials across three reset seeds, 600/1000 Hz and 16/24 solver iterations. There were no falls; mean forward travel was 234.6–239.8 mm, within −0.8% to +1.4% of the default setup. Open-loop lateral drift reached 58.2 mm, so straight walking still benefits from feedback. An eight-generation search evaluated 98 real episodes and improved 14-second travel from 112.6 to 146.1 mm on its training seed; the 31.2% late-speed gain is an in-sample result, not held-out or hardware validation. Exact candidates are in the [training record](validation/r06-locomotion-training-results.json).

Run new longer checks against the prepared current assets from the repository root. Reproducing a historical result requires the matching recorded CAD, controller and runtime hashes; a new run against R08 is a new experiment:

```sh
node --experimental-strip-types viewer/scripts/verification/open-loop.mjs
node --experimental-strip-types viewer/scripts/verification/training.mjs
```

## Image-guided approach

The synthetic camera uses 96 × 72 pixels, a 50° vertical field of view and the modeled head/lens transform. A color heuristic extracts the largest magenta region's bearing and width. The actor receives those image measurements, gait time and issued neck-command history; it receives no target coordinates, body pose or joint-angle telemetry.

Drag the magenta block or enable **Place target on ground** and click the floor. Sliders also position it precisely in a forward training area: 160–600 mm ahead and up to 400 mm either side. The 50 × 50 × 100 mm block stays on the ground. Moving it pauses and resets the episode, invalidating old camera frames. Left/ahead/right presets remain available.

**Search & trial settings** adjusts the head's lost-target sweep (0–45° each side), sweep period (2–12 seconds) and episode limit (15–120 simulated seconds). Search uses camera pixels; no target coordinates reach the actor. Wider or more distant placements can need longer trials and better steering. This bounded frontal workspace is not a demonstrated all-direction navigation system.

**Train to target** compares 12 bounded settings for head tracking, differential hip steering, amplitude and image-width stopping. The default time limit remains 60 seconds. Ground friction, foot friction and mass scale are editable; changing them resets old scores while retaining the selected gait. **Save experiment** includes the target, environment, search settings, selected policy, custom-gait draft and measured results.

The matching [R08 approach record](validation/r08-camera-approach.json) contains **12 successful episodes with no falls**, across six target placements and reset seeds 2026 and 42. It includes an initially out-of-view target; completion took **8.55–46.77 simulated seconds**. The evaluator checks canonical and cached camera meshes plus source hashes, so the record identifies the exact R08 geometry and controller tested. This uses the existing controller settings; it is an approach regression run, and training was not rerun for R08.

The historical [R07 approach record](validation/r07-camera-approach.json) contains **12 successful episodes** across six positions and two reset seeds. It includes 280 mm-forward / 80 mm-left, 240 mm-forward / 100 mm-right, and an initially out-of-view 180 mm-forward / 160 mm-left target. Completion took 8.65–29.55 simulated seconds, with no falls. These finite cases do not prove every placement or custom gait succeeds.

The historical [R07 camera search](validation/r07-camera-learning.json) evaluates 12 candidates: eight succeed and four time out, with no falls. The selected candidate improves score by 0.71 over the already-working initial controller and succeeds in all six held-out target/seed cases. The offline camera uses exact CAD triangle intersections accelerated by a BVH; regression checks compare hits with ordinary triangle raycasting. Interactive WebGL and pointer-drag QA remain separate from these automated tests.

The environment scores signed physical closing and retained progress, rather than apparent image area. Success requires at least 25 mm progress, a body-COM range of 110–130 mm, body heading within 20°, tilt within 15°, and 1.5 continuous seconds meeting those requirements. The controller's stop latch uses only filtered apparent width. Turning the head to look at the object while standing still cannot satisfy success.

The historical [R06 camera search record](validation/r06-camera-learning.json) evaluates all 12 candidate settings: eight succeed and four time out, with no falls. The selected candidate improves score from 16.75 to 17.38 and succeeds in all six held-out target/seed cases. The starting policy already succeeds; this demonstrates parameter refinement, not learning approach from scratch. The reusable search harness is `node --experimental-strip-types viewer/scripts/verification/camera-learning.mjs`, run from the repository root after preparing matching viewer assets. It records the current source and asset hashes; running it on R08 would create a new training experiment, not reproduce the historical record. No such R08 training result is supplied. Default parameters remain the reference settings.

Each image carries the episode ID and exact simulated frame time. A matching image advances six 60 Hz command updates, with 600 Hz physics underneath. Missing or stale images do not advance time or accrue dwell/reward. Training can render faster than real time; playback captures at roughly 10 Hz. Switching workspace tabs pauses the experiment. **Save experiment** exports the environment, controller and measured results, not a hardware or Isaac policy.

Regression tests use the actual CAD triangle meshes to form camera pixels with occlusion, then run the same controller and goal logic across ahead/left/right targets and two seeds. Worker tests separately verify stale-image rejection, physical scoring and real candidate evaluation. This is geometric camera testing; interactive WebGL QA, real camera lighting/latency and physical hardware remain unverified.

```sh
cd viewer
npm ci
npm test
npm run build
node --experimental-strip-types scripts/evaluate-approach.mjs
```

The historical [R06 six-episode record](validation/r06-camera-approach.json) reports six successes in 7.77–9.47 simulated seconds after the R06 mass update. The evaluator writes reproducible parameters, asset hash and episode traces under ignored `work/`. Re-run it whenever CAD, contact geometry, camera optics or controllers change.

## Isaac Lab scaffold

The existing API target is **Isaac Lab v2.3.2 with Isaac Sim 5.1**, as listed in its [compatibility table](https://github.com/isaac-sim/IsaacLab/tree/v2.3.2#isaac-sim-version-dependency). This is the scaffold's target, not a recommendation to install an obsolete runtime. Migration to a current release requires API review and a real import/environment smoke test before changing that claim.

### Articulation and units

| Joint order | Parent → child | Axis | Nominal limit |
|---|---|---|---|
| `left_hip` | body → left_leg | local Y | ±12° |
| `right_hip` | body → right_leg | local Y | ±12° |
| `neck_yaw` | body → head | local Z | ±45° |
| `jaw_pitch` | head → jaw | local Y | 0–12° |

The body is a floating rigid body. CAD axes are X forward, Y left, Z up. Lengths/meshes are millimetres; export converts translations and COM once to metres and uses mesh scale 0.001. Mass is kilograms and inertia is kg·m². Component inertia tensors are combined about link COMs using the parallel-axis theorem. Servo cases belong to the link holding the case. The four separately modeled output shafts belong to their driven links and rotate with the direct spline sockets, which are part of the rotating printed legs, neck carrier and jaw.

Each curved sole uses a two-dimensional grid of tangent boxes, with rounded corner cells inset and slight overlap to reduce gaps. Other links use simple interior collision primitives. These approximate contact geometry and omit some exterior surfaces; inspect cooking, seams and fall contacts in the simulator. The initial physics step is 2 ms, command interval 20 ms, contact offset 0.2 mm, rest offset zero. Compare 1 ms and finer sole segmentation before accepting behavior.

### Servo and observation assumptions

The policy produces four normalized position commands. The simulated internal servo plant adds command delay, lag, backlash, bounded gains and a speed-dependent effort limit. Initial priors include 0–40 ms transport delay, 20–80 ms lag, 0.008–0.035 rad backlash, 0.06–0.11 N·m zero-speed effort ceiling and a 3 rad/s command slew limit. These are unmeasured modeling choices; stall torque is not a continuous rating. The model has no thermal, supply brownout or measured electrical plant.

The actor receives four frames of 14 values: body gyro XYZ, projected gravity XYZ, four requested motion/pose commands and four issued servo commands. It receives no measured joint angle/velocity, root linear velocity, foot contact or simulation phase. A stock three-wire MG90S provides no joint-angle telemetry. Firmware would need matching ordering, normalization, history reset, joint signs, zero offsets, safe limits and slew handling. No such firmware is included.

Friction, restitution, mass scale and actuator properties are randomized around uncalibrated priors. Calibrate servo neutral/endpoints and loaded lag with an external pointer or camera; log commands, voltage, current and temperature. Identify IMU axes/filter delay, link mass and surface/tread behavior, then validate on separate sequences. Two hip axes support a low-speed rocking/shuffling experiment, not general humanoid foot placement or recovery.

### Reproduce and run

First complete the [local CAD and asset derivation](build.md). All generated outputs default to `build/local/`; an explicit `MICRODUCKLING_BUILD_ROOT` changes that root consistently for CAD, audits and simulation. The source and downloaded reference cache remain in the repository.

Static steps use ordinary Python after the FreeCAD derivation:

```sh
python simulation/export_urdf.py
python simulation/validate_assets.py
python simulation/assess_balance.py
python -m unittest discover -s simulation/tests -v
```

For a compatible, separately installed Isaac Lab checkout, set `$lab` to its directory and run from the repository root:

```powershell
& "$lab/isaaclab.bat" -p simulation/import_asset.py --headless
& "$lab/isaaclab.bat" -p simulation/smoke_isaac.py --seconds 5 --headless
& "$lab/isaaclab.bat" -p simulation/run_rl.py --isaaclab-root $lab --mode train --task MicroDuckling-Flat-v0 --num_envs 64 --max_iterations 10 --headless
```

Linux uses `isaaclab.sh` with the corresponding arguments. The wrapper delegates to the installed RSL-RL workflow; it does not bundle or modify it. Import checks compare link masses, COMs and full inertia tensors. Training requires matching import evidence and a current bounded smoke report; changed CAD, meshes, nested USD assets or environment source invalidate stale evidence. Ten training iterations would test the pipeline, not prove a useful gait.

Inspect the scene visibly and record falls, travel, slip, tracking error, torque and sustained load over multiple seeds and held-out parameters. Complete power shutdown and mechanical qualification before attempting constrained physical deployment.

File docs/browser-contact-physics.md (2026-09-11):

# Browser contact physics and numerical checks

The browser uses Rapier rigid-body integration with gravity, bounded joint motors and Coulomb contact friction. Movement is produced by those forces. Display geometry, collision geometry and CAD-estimated mass/inertia are separate inputs. Robot self-collision remains disabled because the interior body/head/leg envelopes are approximate.

The recommended browser settings are continuous convex sole hulls, a **1/600 s physics step**, **16 solver iterations**, gravity 9.81 m/s², foot friction 0.9, ground friction 0.7, other-part friction 0.35, mass scale 1, allowed penetration error 0.05 mm and prediction distance 0.2 mm. Commands update at 60 Hz. Friction uses the explicit `Min` combination rule, giving effective foot-ground friction `min(0.9, ground friction)`. These material and actuator values are unmeasured priors. Rapier uses Coulomb friction without separate static/dynamic coefficients. [Rapier collider documentation](https://rapier.rs/docs/user_guides/javascript/colliders/)

Each sole hull uses the original public tread mesh vertices converted from assembly millimetres to link-local metres, rounded to 1e-8 m and deduplicated. Rapier constructs one convex hull per tread. This leaves nine robot colliders plus ground; the 109 legacy robot boxes remain available for explicit numerical comparison. Changing collision mode does not add or remove the specified link mass. A faceted convex hull is still an approximation to a continuous curved rubber sole.

## Contact readouts

| Readout | Meaning |
|---|---|
| Mass and weight | Sum of simulated link masses; weight is mass × configured gravity. Uniform mass scaling also scales inertia and leaves local COM positions unchanged. |
| World COM | Mass-weighted live rigid-body centres of mass. |
| Support from momentum balance | Change in total robot linear momentum minus gravity and approximate linear drag, divided by elapsed simulated time. |
| Foot load estimate | Total support allocated according to each sole's share of raw normal contact impulses. This is an estimated split, not an independently measured foot force. |
| Slip | Actual tangential velocity of the body at its contact points relative to stationary ground; foot values are impulse-weighted averages. |
| Contact markers | Last fixed-substep contact locations. These are points, not pressure patches. |

The support calculation compensates the model's 0.01/s linear damping using a trapezoidal approximation. It reports ground support as unavailable when the robot also loads the target obstacle, because total momentum cannot isolate the two supports. Force/slip averages cover the actual fixed substeps executed by the public update call. Contact telemetry is for inspection and evaluation; it is excluded from policy observations.

Rapier 0.20.0 raw per-contact impulses and contact-force events were unsuitable as direct force readouts in these checks. A resting 1 kg box returned `mg × (1 + 1 / solverIterations)` for impulse divided by timestep and for force events: 11.03625 N at eight iterations despite negligible vertical acceleration and 9.81 N weight. Per-point tangential getters returned zero while friction changed motion. The engine preserves raw values for diagnostics, displays tangential force as unavailable, and does not rescale raw impulses to the expected weight. Contact ordering was checked against the installed API and [Rapier's manifold documentation](https://rapier.rs/docs/user_guides/javascript/advanced_collision_detection/); upstream [impulse accumulation source](https://github.com/dimforge/rapier/blob/3e12c2679cb1940a876bde93af9cec0cf2f57944/src/dynamics/solver/contact_constraint/contact_with_coulomb_friction.rs) is linked for investigation. The numerical behavior is a local observation, not an upstream acknowledgement of a defect.

## Recorded numerical evidence

The 11 September 2026 contact audit used a 0.257281 kg CAD model. After two seconds settling and two seconds sampling, support from momentum balance was 2.52387 N against 2.52393 N weight. At half mass it was 1.26153 N against 1.26196 N; at 1.5 times mass it was about 3.7875 N against 3.7859 N. Removing the ground caused free fall. Zero gravity with internal motor commands preserved total COM position within 2 μm.

An independent sliding-box check with rotation locked measured deceleration 3.92404, 6.86703 and 8.82897 m/s² at friction coefficients 0.4, 0.7 and 0.9. These match `coefficient × gravity` within 0.001 m/s². Zero friction preserved horizontal velocity. This verifies that friction changes the dynamics even though the tangential API readout was unavailable.

A fixed diagnostic rocking gait was run for 30 seconds at seed 2026, with 0.002-radian reset perturbations and 60 Hz commands:

| Sole / solver iterations | Travel at 300 Hz | At 600 Hz | At 1,000 Hz |
|---|---:|---:|---:|
| Legacy boxes / 8 | 62.77 mm | 27.64 mm | 21.41 mm |
| Convex / 8 | 22.82 mm | 8.74 mm | 10.33 mm |
| Convex / 16 | 7.45 mm | 8.05 mm | 8.12 mm |

All nine runs stayed upright. The convex/16 setting showed materially better timestep convergence; its late forward speeds were 0.697, 0.662 and 0.609 mm/s respectively. This table checks numerical sensitivity using one fixed diagnostic controller. It is not a hardware validation or a claim about the best controller found by later search.

The recorded hull fixture's SHA-256 is `676452fc96ee216c69a5a8725e577ac93b4c04438c0cc9da98a71ff167152f09`; source CAD hash is `2bfee66a13c8f88110521157c7b271f15e3d4d98a9cedfb0e5e9f0a088842ed5`. These identify the geometry used for this numerical comparison. Subsequent CAD or dynamics changes require new evidence; a matching joint command file alone does not reproduce a changed plant.

## Regeneration

After rebuilding CAD and running `simulation/derive_manifest.py`, derive a separate browser review asset from the matching public tread meshes:

```sh
python simulation/browser/derive_asset.py build/local/cad/manifest.json build/browser-check/robot-physics.json --mesh-dir cad/meshes
python -m unittest discover -s simulation/tests -v
```

When reviewing a separate public CAD export, use `--mesh-dir build/public-check/cad/meshes`. Inspect the output before intentionally replacing `simulation/browser/robot-physics.json`. The generator records source-manifest and tread hashes, retains the complete physical mass/inertia estimate, and embeds `contactModel.recommendedSettings`. Only original Apache-licensed tread vertices are included. Full local link meshes containing vendor geometry remain excluded from the public asset.

Changing friction, mass, timestep, solver settings or contact geometry invalidates previously selected training results. Compare held-out seeds, sustained progress, falls, slip and finer numerical settings before interpreting a simulated controller as robust. Physical motors, printed parts, actual tread material, camera latency and power supply behavior still require measurement.

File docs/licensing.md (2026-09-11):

# License scope and publication boundaries

MicroDuckling uses per-asset licenses. Original source, documentation and independently generated mechanical designs use the [Apache License 2.0](../LICENSE). That license does not replace the Adafruit hardware license or the MIT notices on adapted shadcn UI files.

| Published material | License and scope |
|---|---|
| Mechanical native CAD, printed-part exports and original mechanical viewer meshes | Apache-2.0. These exports exclude the two separately supplied electronics visuals. |
| `components/meshes/IMU.json` | CC-BY-SA-3.0 adaptations of Adafruit PCB designs. |
| `components/meshes/Buck_0.json` | Apache-2.0 original visual approximations of Pololu regulators, authored from dimensions and generic primitives; not conversions of manufacturer STEP files. |
| Electronics-inclusive assembled/exploded renders and their thumbnails | CC-BY-SA-3.0 composite artwork; retain the Adafruit and MicroDuckling credits below. This does not relicense the separate mechanical source files. |
| Adapted shadcn UI files | MIT; exact paths are listed in [third-party notices](../THIRD_PARTY_NOTICES.md). |
| AI-generated mascot in `assets/brand/` | Offered separately under Apache-2.0; see its [provenance](../assets/brand/PROVENANCE.md). It is not part of the Adafruit-derived artwork. |

The Adafruit IMU design is by **Limor Fried/Ladyada for Adafruit Industries**. MicroDuckling contributors adapted Eagle outlines, holes, pads and package positions into colored 3D meshes, added approximate component heights and fitted connectors, and positioned the boards in the robot. These are adaptations, not manufacturer mechanical CAD. [Component attribution](../components/NOTICE.json) records source titles, URLs, hashes and changes; complete upstream READMEs and licenses are preserved under `components/licenses/`. Adafruit's hardware notices select [CC-BY-SA 3.0](https://creativecommons.org/licenses/by-sa/3.0/). The additional LSM6DS3 MIT notice is retained and is not treated as an override of those hardware terms.

The viewer combines separately licensed component records with the mechanical assets. Keep the component notices and license information when redistributing that collection. Assembled/exploded image assets incorporating the Adafruit adaptations, including derivative thumbnails, are distributed as CC-BY-SA-3.0 composites. Credit MicroDuckling contributors for the robot, adaptations and rendering, and Limor Fried/Ladyada for Adafruit Industries for the IMU board design; link the [component notice](../components/NOTICE.json) and license. [Render provenance](../assets/renders/render_provenance.json) identifies the assets and their inputs. A format change or rasterization does not remove upstream rights.

Pololu's manufacturer STEP models remain local reference inputs: no general redistribution grant was established for those downloaded files. The public regulator visuals use independently authored boxes, cylinders, holes and generic component arrangements informed by published dimensions and photographs. They include no manufacturer STEP geometry, photograph, drawing image, logo or silkscreen. Their Apache license covers the new representation, not rights in the commercial hardware or its trademarks.

Microduck is the inspiration, with credit to Pollen Robotics and Hugging Face. Its repositories provide Apache-licensed software, while Pollen's [press kit](https://pollen-robotics.com/microduck/press-kit/) limits the open-source statement to software. This repository distributes no official Microduck meshes, policies, product photography or branding. It is an independent hobby project with no upstream affiliation or endorsement.

Installed dependencies retain their own licenses, including the Apache-2.0 [Rapier physics engine](https://github.com/dimforge/rapier/blob/master/LICENSE). See [third-party notices](../THIRD_PARTY_NOTICES.md) for details.

Before publishing a changed build, use the public export/validation workflow and retain the per-asset notices. `build/local/` and `references/components_r02/` remain ignored. Full local scenes and generated body-link meshes can still contain manufacturer STEP geometry; restoring separately licensed viewer assets does not authorize publishing those aggregates.

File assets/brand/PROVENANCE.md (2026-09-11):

# MicroDuckling mascot provenance

- Asset: microduckling-mascot.png
- Created: 2026-09-11
- Generator: OpenAI built-in image_gen tool; no fallback CLI used.
- Purpose: an original independent mascot for the public open-source MicroDuckling hobby robot project.
- Design reference: the project’s R05 CAD, inspected before prompt authoring. The generation used the written prompt only.
- Visual review: one camera lens; white faceted large head and smaller torso; short orange beak; two orange continuous curved rocker feet; no arms, wings, tail, toes, text, watermark, or third-party brand elements visible. Vector-like raster artwork, with modest facet tonal variation. Generated image copied byte-for-byte, with no post-generation editing.

## Exact generation prompt

Use case: logo-brand
Asset type: one finished square mascot logo for the public open-source MicroDuckling hobby robot project, readable as a small GitHub avatar.
Primary request: Create an original cute, polished robot-duck mascot mark inspired by the inspected MicroDuckling CAD design. Single mascot, no text.
Subject: a compact squat robot in a friendly three-quarter view facing slightly right. An oversized white faceted cuboid head with clipped/chamfered corners, a single dark navy front faceplate, ONE circular camera lens centered on that faceplate with an orange octagonal lens bezel and a small white lens glint. The only eye-like element is this single camera lens. A short orange flat beak-like shelf below the faceplate. A narrow simple neck, a smaller white faceted rounded-rectangular body, and exactly two orange smooth curved rocker feet with short orange supports. The feet are broad crescent-like rocking soles, continuous smooth silhouettes without toes. Preserve the characteristic oversized box head, single camera face, compact torso, and two rocker feet of the physical robot.
Style/medium: crisp professional vector-like flat emblem, confident bold dark navy outer outlines, restrained clean internal linework, simple large shapes. Cute through the proportions and gentle curious head tilt. White panels with only minimal pale cool-gray facet shading, vivid warm orange accents, deep navy face and outlines. Flat solid colors, no gradients, no 3D render, no texture.
Composition/framing: centered isolated full-body mark on a square canvas, compact balanced silhouette occupying about 82 percent of canvas with generous even transparent padding. Every outline and both feet fully inside the frame. No enclosing badge, no scenery, no platform, no drop shadow.
Background: actual transparent alpha background, no colored background and no checkerboard drawn into the image.
Constraints: exactly one mascot; exactly one camera lens; exactly two rocker feet; no wings, no tail, no feathers, no toes, no arms, no hands, no second eye. No letters, words, watermark, or signature. Make an original independent project identity; no Hugging Face emoji or logo, no NVIDIA logo or other third-party branding. Deliver one finished logo, not a contact sheet or multiple variants.

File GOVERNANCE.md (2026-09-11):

# Project governance

MicroDuckling is a community hobby robotics project maintained by [itchson](https://github.com/itchson). The aim is a small, affordable robot that is approachable to build, repair and understand, with a path toward learning locomotion in NVIDIA Isaac Sim.

The repository begins with the R05 design prototype. Publishing it invites collaboration; it does not turn the current CAD into a qualified kit or establish successful walking.

## Roles and decisions

Anyone can report results, propose ideas, review changes or submit a pull request. The maintainer currently manages the repository, reviews and merges changes, sets release scope and moderates project spaces. There is no formal steering committee, membership requirement or voting process.

Technical decisions should be discussed in issues and pull requests so that contributors can follow the reasoning. Small changes can be proposed directly in a pull request. For changes that affect compatibility, cost, component availability or several subsystems, describe the alternatives and consequences early.

The maintainer makes the final decision on what enters the main repository. Review weighs:

- Evidence from reproducible checks and physical measurements.
- Build difficulty, part availability, cost and repairability.
- Compatibility with the rest of the robot and the effort to maintain the change.
- Clear documentation of assumptions, tradeoffs and remaining unknowns.

A promising idea may remain a branch or experiment until there is enough evidence to adopt it. Contributors can disagree respectfully, offer more evidence or continue an alternative in their own fork under the applicable licenses.

## Releases and project direction

The [roadmap](ROADMAP.md) describes intended stages, not delivery commitments. Priorities may change as physical builds expose problems or contributors bring new evidence. There are no promised review times or release dates.

Release notes should identify the design revision, relevant changes and checks actually performed. Hardware fit, electrical operation, simulation execution, training and physical walking are separate claims and should be reported separately. A result on one component batch or test surface should not be presented as universal.

If the contributor community grows, repository access and additional maintainer roles can be discussed publicly and documented here. This document reflects the current arrangement rather than a promised future organization.

## Participation and questions

Use an issue or pull request for project questions and proposals. Follow the [contribution guide](CONTRIBUTING.md) and [community conduct guidelines](CODE_OF_CONDUCT.md). For a concern that should not be public, consult the contact options available on the maintainer's GitHub profile; do not put private information in an issue.

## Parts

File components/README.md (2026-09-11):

# Separately licensed component visuals

Two assets complete the active R08 viewer: the body IMU and shared 5 V regulator. The PCA9685 and separate logic regulator were removed from the robot. Coordinates are assembly millimetres. Keep each mesh with its record, attribution and license.

| Asset | Representation | License |
|---|---|---|
| `meshes/IMU.json` | Adafruit LSM6DS3TR-C board adapted from Eagle geometry; generic component heights and fitted connectors | CC-BY-SA-3.0 |
| `meshes/Buck_0.json` | Original dimension-based approximation of the Pololu D24V50F5 shared regulator | Apache-2.0 |

The IMU design is by **Limor Fried/Ladyada for Adafruit Industries**. MicroDuckling contributors adapted its board outlines, holes, pads and package placements to colored 3D meshes, added generic heights and connectors, and positioned it in the assembly. See [machine-readable attribution](NOTICE.json), the [upstream README](licenses/adafruit-lsm6ds3/README.md), [hardware license](licenses/adafruit-lsm6ds3/license.txt) and [additional upstream MIT notice](licenses/adafruit-lsm6ds3/LICENSE). The historical PCA9685 upstream notices are retained for earlier revisions; its mesh was removed in R06.

The regulator visual uses independently authored primitives, without reading or converting manufacturer STEP geometry. Its PCB outline and nominal envelope use the [manufacturer dimensions](https://www.pololu.com/file/0J1436/d24v50f5-step-down-voltage-regulator-dimensions.pdf); [product photographs](https://www.pololu.com/product/2851/pictures) informed a generic component arrangement. Detail and placement are approximate. Its mass and COM retain the engineering assembly estimates, so adding the visual does not add another regulator's weight. Product names identify the represented hardware and imply no endorsement.

These display meshes are not substitutes for supplier mechanical drawings, electrical validation or physical measurements. The complete native mechanical model and printed-part STEP remain separate from these assets.

Regenerate with FreeCAD's Python after building the source assembly:

```sh
python components/generate_electronics_visuals.py --cad build/local/cad --notices references/components_r02/notices --output components
```

The script reads the assembly records, the IMU mesh and the explicitly named upstream notice files; it generates the regulator from original source primitives. Ship `licenses/Apache-2.0.txt`, the applicable Adafruit notices and this README with the outputs. `records.json`, `NOTICE.json` and `validation.json` preserve physical estimates, material groups, bounds and provenance.

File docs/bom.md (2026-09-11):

# Bill of materials and sourcing

The revised electrical layout uses **one shared 5 V regulator**, four MG90S servos and an ESP32-CAM issuing the servo signals directly. **PCA9685 and the second logic regulator are excluded from the purchase list.** The 2S battery and an IMU remain. The retained regulator geometry is Buck_0, based on Pololu D24V50F5; a cheaper regulator needs a measured mount and a loaded supply test.

Using the project's **A$20 estimate for four servos** and **A$30 estimate for the camera**, the proposed build is about **A$100–110 with the budget regulator candidate**. Keeping the dimensioned Pololu regulator makes the same budget about **A$120–142**. These totals include a battery, budget IMU, consumed hardware and print material, and exclude shipping, charger and tools. They do not price the exact branded IMU or guarantee that alternative parts fit the CAD.

## Revised budget

Australian prices checked **11 September 2026**; project estimates and material allowances are labelled separately.

| Qty | Part | Line cost | Basis / limitation |
|---:|---|---:|---|
| 4 | Positional MG90S-type servos and matching center screws | A$20 | Project estimate for all four. Measure the actual cases, output splines and peak current; stock horn arms are not installed. |
| 1 | ESP32-CAM with OV2640 camera | A$30 | Project estimate; [Phipps OV2640 board](https://www.phippselectronics.com/product/esp32-cam-wifi-bluethooth-development-board-with-ov2640-camera-module/) was A$29.95. |
| 1 | 2S 450 mAh LiPo candidate | A$16.95 | [Aus Electronics Direct PB4174](https://www.auselectronicsdirect.com.au/7.4v-450mah-lipo-2s-battery-pack-with-jst-connecto), **56 × 30 × 10 mm**. It does not match the existing 43 × 23 × 13 mm tray reference; connector/current suitability also needs checking. |
| 1 | Shared 5 V regulator candidate, DFRobot DFR0753 | A$16.80 | [Core Electronics](https://core-electronics.com.au/dc-dc-buck-converter-6-14v-to-5v-8a.html). Advertised 6–14 V input, up to 8 A output. A cost candidate, not a qualified replacement for the Pololu mount or a verified enclosed 8 A supply. |
| 1 | MPU-6050 IMU candidate | A$4.60 | [Core Electronics](https://core-electronics.com.au/mpu-6050-module-3-axis-gyroscope-acce-lerometer.html). Different mount and driver from the Adafruit reference. |
| — | Fasteners, wire, connectors, disconnect/fuse, capacitors, insulation and tread material | A$8–15 | Allowance for quantities consumed from workshop supplies. Buying complete assortments costs more. |
| — | Printed robot parts and fit coupons | A$3–5 | Material allowance with an existing printer; excludes failures and commercial printing. |

Electronics subtotal: **A$88.35**. With consumed hardware and printing: **A$99.35–108.35**, rounded to A$100–110. No PWM-driver board or second buck converter is counted.

For the retained **Pololu D24V50F5**, replace the A$16.80 candidate line with [Robot Gear's A$37.95](https://www.robotgear.com.au/Product.aspx/Details/1003-5V-5A-Pololu-Step-Down-Voltage-Regulator-D24V50F5) or [Core's A$49.95](https://core-electronics.com.au/pololu-5v-5a-step-down-voltage-regulator-d24v50f5.html). This adds A$21.15–33.15, giving **A$120.50–141.50** with the other assumptions unchanged. It is a geometry reference, not a requirement to buy the more expensive shop's board.

Lower advertised alternatives can reduce the planning total toward **A$80–110**: the earlier [four-servo offer](https://www.ebay.com.au/itm/166481674710) was A$14.99 and the [Zaitronics camera/programmer kit](https://zaitronics.com.au/products/esp32-cam-camera-mb-motherboard-usb-c-version-development-board) is A$16.25. The latter specifies **OV3660**, with a different camera and dispatch lead time. This lower range requires additional selection and fit work.

Charging equipment is separate. A [SkyRC B6neo at FPVFaster](https://www.fpvfaster.com.au/products/skyrc-b6-neo-smart-charger-200w-dc-pd-dual-input?variant=42251956486226) was around **A$52–62**, plus a compatible PD/DC supply and leads if needed. The [manufacturer](https://www.skyrc.com/b6neo-series) lists adjustable charging current and 2S support. Match the delivered pack's charge limit and connectors. Also allow for a 3.3 V logic USB-to-UART programmer when the camera purchase does not include one.

## Retained dimensional references

| Qty | Reference component | CAD / qualification |
|---:|---|---|
| 4 | MG90S with matching centre screws | [TowerPro reference](https://towerpro.com.tw/product/mg90s-3/). Measure all four actual servos. |
| 1 | Ai-Thinker ESP32-CAM with ordinary OV2640 flex camera | [Manufacturer V1.0 datasheet, mirrored](https://wiki.diustou.com/cn/w/upload/b/be/Esp32-cam_product_specification_zh.pdf). Nominal board 27 × 40.5 mm; drawing says 40 mm long. Header rows are 22.86 mm apart at 2.54 mm pitch; no dedicated mounting holes. |
| 1 | Adafruit LSM6DS3TR-C IMU, product 4503 | [Product](https://www.adafruit.com/product/4503). 25.4 × 17.78 mm, two Ø2.5 mm mounts 20.32 mm apart. The A$4.60 MPU-6050 allowance does not buy this exact board. |
| 1 | Pololu D24V50F5, product 2851, Buck_0 | [Manufacturer](https://www.pololu.com/product/2851/specs). 17.78 × 20.32 mm, two diagonal Ø2.18 mm mounts; populated on both sides. Retained reference for the shared 5 V rail. |
| 1 | Gens ace GEA4502S60XT3, 2S 450 mAh | [Manufacturer](https://gensace.de/products/gea4502s60xt3). Existing packaging reference 43 × 23 × 13 mm and 28 g. Confirm delivered pack and connector dimensions. |
| — | Vendor-matched direct-mount retaining screws, M2 assembly screws/nuts and nominal 0.20 mm thrust shim | M2 assembly screws use printed pilots or modeled nut pockets; servo-output center threads remain vendor-specific. Engagement and shim stack require measurement; see [hardware worksheet](hardware-measurements.md). |
| 2 | M2×8 countersunk screws with matching M2 nuts for upper-mouth mount | Nominal 90°/Ø4 mm head reference; included in the consumed-fastener allowance. Verify delivered dimensions and countersink fit. |
| 15 + 2 | Printed parts and fit coupons | cad/stl/, cad/coupons/ and geometry-only cad/3mf/. |

The Adafruit PCA9685 and Pololu D24V10F5 are superseded R05 references, not parts to purchase for the revised direct-PWM/shared-supply layout. The revised CAD omits both; historical reports may retain their names.

The electrical connection and pin allocation are documented separately in [electronics](electronics.md). See [parts and power research](parts-research.md) for current budgeting, thermal/dropout limits and proposed distribution capacitors. Record delivered dimensions and powered results in [hardware measurements](hardware-measurements.md).

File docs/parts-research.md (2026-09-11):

# Parts and shared-supply research

The revised build uses **one 5 V regulator feeding four MG90S servos and the ESP32-CAM**, with separate power branches and common ground. The ESP32 generates four servo command signals directly. The PCA9685 and second logic regulator are removed from the active BOM. Pin allocation and firmware constraints belong in [electronics](electronics.md).

## Cost of the simpler layout

The [BOM](bom.md) now uses the project's A$20 allowance for four servos and A$30 for an OV2640 ESP32-CAM. With an A$16.95 battery, A$16.80 regulator candidate and A$4.60 IMU, electronics total **A$88.35**; consumed hardware and print material bring that to roughly **A$100–110**, excluding shipping, charger and tools. A cheaper camera/servo selection could approach A$80, with different fit and sourcing assumptions.

Buck_0 remains the dimensioned Pololu D24V50F5 reference. Australian prices checked on **11 September 2026** were [A$37.95 at Robot Gear](https://www.robotgear.com.au/Product.aspx/Details/1003-5V-5A-Pololu-Step-Down-Voltage-Regulator-D24V50F5) and [A$49.95 at Core](https://core-electronics.com.au/pololu-5v-5a-step-down-voltage-regulator-d24v50f5.html). Using it instead of the A$16.80 candidate raises the same build allowance to **A$120.50–141.50**. The board establishes a known outline and mounting arrangement; its price is not the minimum cost of supplying the robot.

The former branded combination—Adafruit PCA9685, D24V50F5 and D24V10F5—was A$98.15 from one shop before servos or camera. Two of those boards are no longer required. The cheaper [DFRobot DFR0753](https://www.dfrobot.com/product-2162.html) is a candidate pending measured dimensions, mounting, wiring and electrical qualification; its advertised efficiency is specified at **12 V input and full load**, outside this 2S operating point.

## Voltage, current and heat

The retained battery architecture is **2S LiPo: about 7.4 V nominal, 8.4 V fully charged**. The buck converter supplies regulated 5 V to both branches; the camera board's onboard regulator supplies its internal 3.3 V electronics. Servo motor current comes directly from the 5 V distribution, not through ESP32 GPIO or camera-board power traces. The [Ai-Thinker V1.0 datasheet](https://wiki.diustou.com/cn/w/upload/b/be/Esp32-cam_product_specification_zh.pdf) specifies **4.75–5.25 V** at the ESP32-CAM supply, and lists 180 mA with its flash LED off and 310 mA with full flash brightness. These operating figures are not guaranteed transient maxima.

TowerPro's [MG90S specification](https://towerpro.com.tw/product/mg90s-3/) gives torque/speed information but **no stall-current figure**. A guaranteed four-servo peak cannot be calculated from that page. Reserve **0.5 A for camera, Wi-Fi and logic as a design allowance**, then measure the actual servo batch. These examples show the sensitivity; the per-servo currents are assumptions, not established MG90S bounds:

| Assumed simultaneous peak per servo | Four servos | Plus 0.5 A logic allowance | 5 V output power |
|---:|---:|---:|---:|
| 0.5 A | 2 A | 2.5 A | 12.5 W |
| 1.0 A | 4 A | 4.5 A | 22.5 W |
| 1.5 A | 6 A | 6.5 A | 32.5 W |

Peaks can coincide during startup, abrupt reversals or a mechanical obstruction. The upper example exceeds a nominal 5 A supply. Espressif recommends at least 500 mA capacity for the **ESP32 chip's 3.3 V supply**; this supports allowing headroom but is not measured 5 V camera-board consumption. [Espressif hardware guidelines](https://docs.espressif.com/projects/esp-hardware-design-guidelines/en/latest/esp32/schematic-checklist.html)

Pololu labels the D24V50F5's **5 A as typical and thermally limited**. Its specification lists about 6 V minimum input at light load, rising to about 6.2 V at 5 A; leave additional margin for wiring loss, battery sag and actual dropout behavior. A nearly empty 2S pack at 6 V cannot be assumed to maintain a clean 5 V rail under high load. Establish the battery stop threshold from the pack limits and loaded voltage measurements, rather than waiting for the camera to brown out. [Pololu specifications](https://www.pololu.com/product/2851/specs)

For illustration, **4.5 A at 5 V and 90% efficiency** requires about **3.38 A from 7.4 V**, rising to **3.91 A at 6.4 V**, and dissipates **2.5 W in the regulator**. These are calculated examples using `Iin = Vout × Iout / (Vin × efficiency)` and `loss = Pout × (1/efficiency − 1)`, not measured robot performance. Pololu's advertised 85–95% efficiency implies roughly 1.2–4.0 W loss at that output power. Enclosure temperature, airflow and connection resistance determine the usable sustained load. A short 5 A bench demonstration does not establish a continuous enclosed rating. [Pololu product description](https://www.pololu.com/product/2851)

## Proposed power distribution

```mermaid
flowchart LR
  B["2S battery"] --> F["Fuse and disconnect"] --> R["One 5 V buck: Buck_0 reference"]
  R --> S["Short 5 V / GND distribution point"]
  S --> P["Servo branch: four MG90S power pairs"]
  S --> C["Camera branch: ESP32-CAM 5V / GND"]
  C -. "Four command signals" .-> P
  C -. "3.3 V and I2C" .-> I["IMU"]
  P --- CP["470–1000 µF bulk across servo bus"]
  C --- CC["100–470 µF bulk at camera entry"]
```

Give the camera its own positive/return pair from the distribution point so servo return current does not flow along its ground lead. Start with **470–1000 µF, at least 10 V** bulk capacitance at the servo bus and **100–470 µF, at least 10 V** at the camera's 5 V entry. Keep the board's ceramic decoupling; 10 µF plus 0.1 µF close to a branch entry are reasonable additional starting values where absent. Check startup/inrush, stability and transient response with the chosen regulator. Adafruit suggests about 100 µF per servo as an initial bulk estimate, and Espressif specifies local 10 µF/0.1 µF decoupling for its chip rails. These references support the approach; the additional module-level values here are engineering starting points. [Adafruit servo power guide](https://learn.adafruit.com/16-channel-pwm-servo-driver/hooking-it-up), [Espressif guidelines](https://docs.espressif.com/projects/esp-hardware-design-guidelines/en/latest/esp32/schematic-checklist.html)

Use short battery leads. A roughly **100 µF, 25 V electrolytic near regulator VIN** is an input-transient starting point, especially with long leads or a switch; verify its effect on the actual circuit. Pololu demonstrates how lead inductance and low-ESR input capacitors can cause switching spikes, and how additional electrolytic capacitance can damp them. [Pololu input-transient measurements](https://www.pololu.com/docs/0J16/5)

Bulk capacitance does not replace supply current: `ΔV = I × Δt / C` means even 1000 µF loses 1 V while supplying a 1 A deficit for only 1 ms. Check 5 V at the camera header during coordinated servo starts/reversals, camera streaming and low-battery loading, and log regulator/connector temperature over sustained operation. Qualify the shared supply by those results; a regulator's current headline alone is insufficient.

## IMU and leg motion

Manual servo poses can run without an IMU. The planned balance policy consumes angular velocity and estimated gravity direction, so an IMU remains in the learning-oriented BOM. A budget MPU-6050 needs its own mount, driver and calibration; it does not provide servo joint-angle feedback. See [simulation observations](simulation.md).

Both hips rotate about model +Y. Coordinated pitch can incline the torso relative to supported feet, giving a bow-like motion; actual motion depends on rolling contact, mass distribution and balance. The current mechanical envelope remains **−12° to +12° per hip**. The servo's advertised rotation range does not establish additional clearance. [Joint derivation](../simulation/derive_manifest.py), [CAD generator](../src/build_cad.py)

Record delivered dimensions and electrical measurements in [hardware measurements](hardware-measurements.md). Alternative boards and packs remain candidates until their fit and loaded behavior are checked.

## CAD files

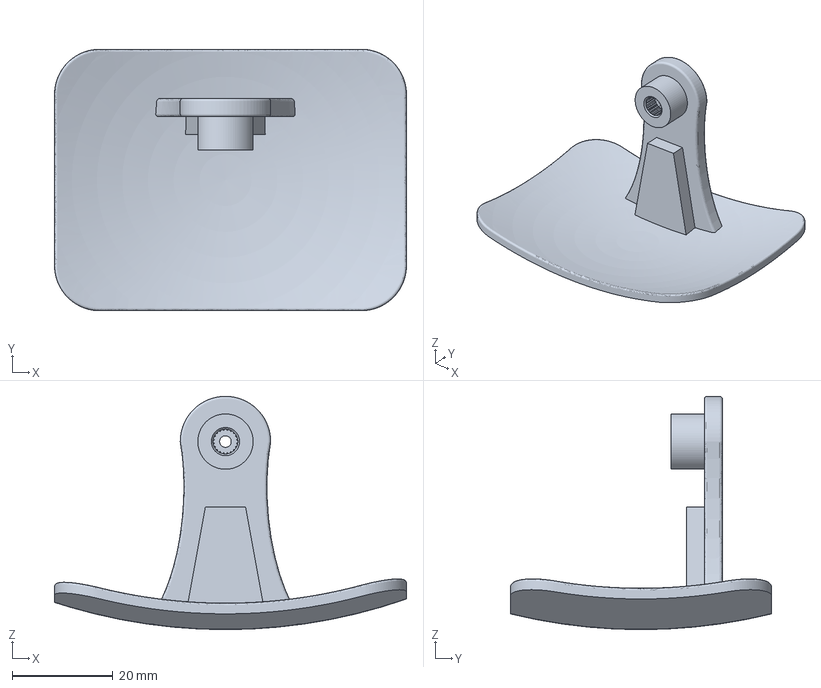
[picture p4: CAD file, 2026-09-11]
cad/3mf/LegFootLeft.3mf
70.0 x 52.0 x 46.4 mm

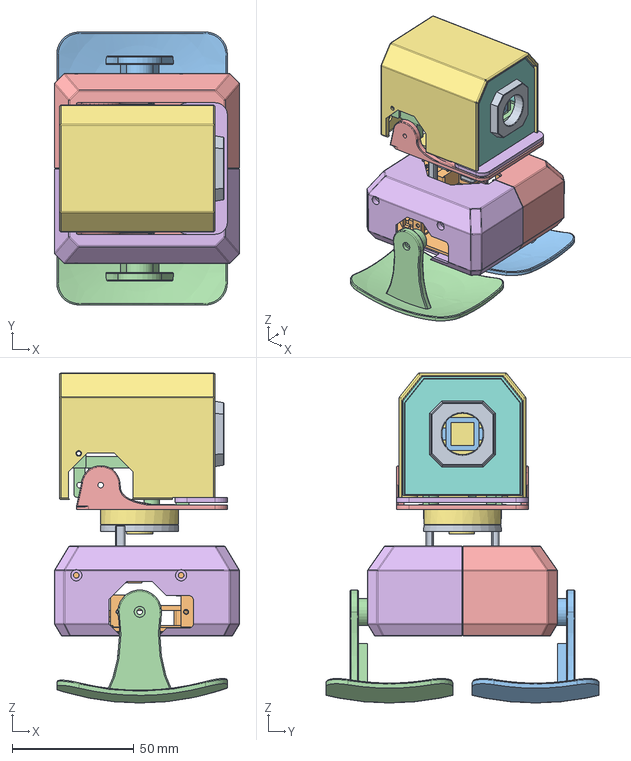
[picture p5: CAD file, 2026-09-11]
cad/MicroDuckling_R05_printed.step
76.0 x 112.0 x 135.4 mm

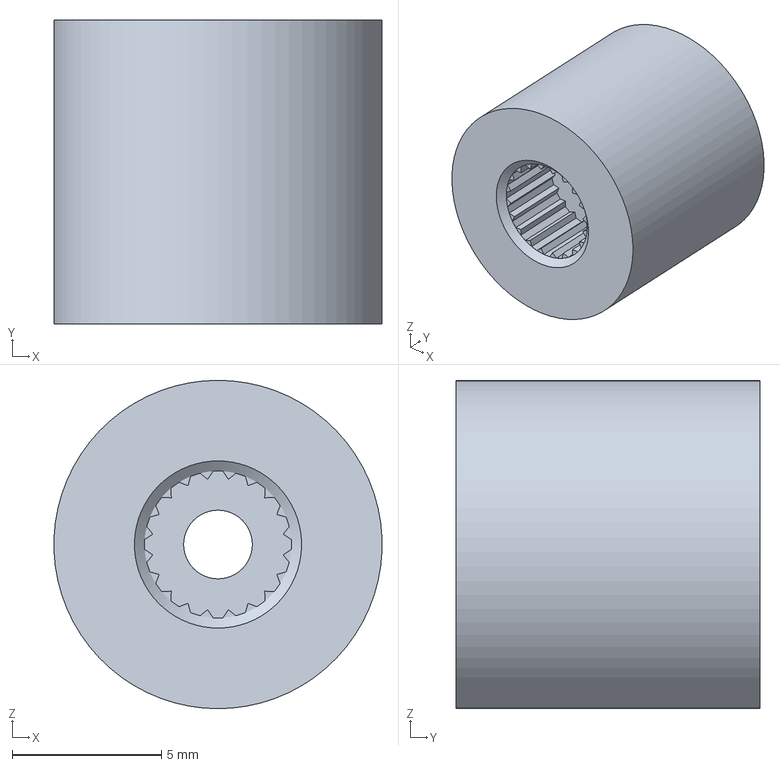
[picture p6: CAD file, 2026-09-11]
cad/3mf/SplineFitCoupon.3mf
11.0 x 10.2 x 11.0 mm

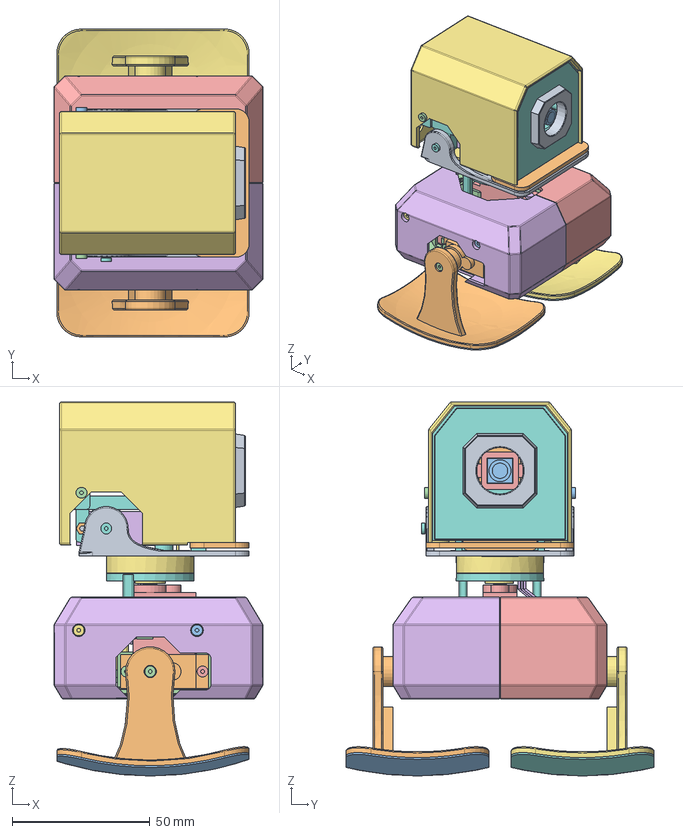
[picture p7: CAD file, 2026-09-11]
cad/MicroDuckling_R05_mechanical.FCStd
76.0 x 112.0 x 136.0 mm
ServoLeft
ServoRight
OutputSplineLeft
OutputSplineRight
ServoNeck
OutputSplineNeck
Battery
FixedNeckSupport
ThrustShim
Buck_0MountScrew0
Buck_0MountScrew1
Chassis
BatteryStrap
BatteryPad
LegFootLeft
TreadLeft
ShaftScrewLeft
LegFootRight
TreadRight
ShaftScrewRight
BodyScrew-261
BodyNut-261
BodyScrew-26-1
BodyNut-26-1
BodyScrew171
BodyNut171
BodyScrew17-1
BodyNut17-1
BodyShellLeft
BodyShellRight
NeckCarrier
FacePanel
CameraRing
ESP32CAM
OV2640Camera
CameraBoardClamp
CameraCradle
ServoMouth
OutputSplineMouth
HeadFrame
Jaw
UpperMouthBase
UpperMouthScrewLeft
UpperMouthNutLeft
UpperMouthScrewRight
UpperMouthNutRight
HeadHood
JawPassivePin
JawPassiveLocknut
MouthShaftScrew
HoodScrew1
HoodScrew-1
CameraClampScrew-15
CameraClampScrew15
CameraCradleScrew-12
CameraCradleScrew12
MouthMountScrew0
MouthMountNut0
MouthMountScrew1
MouthMountNut1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

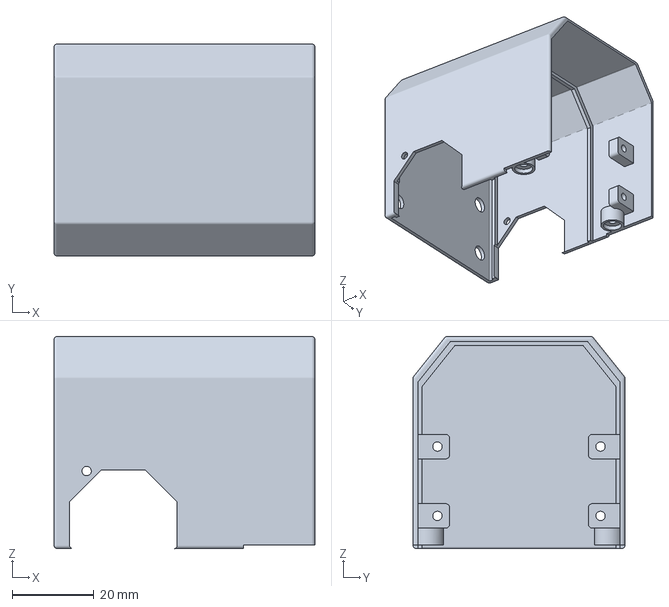
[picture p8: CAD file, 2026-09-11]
cad/3mf/HeadHood.3mf
64.0 x 52.0 x 52.0 mm

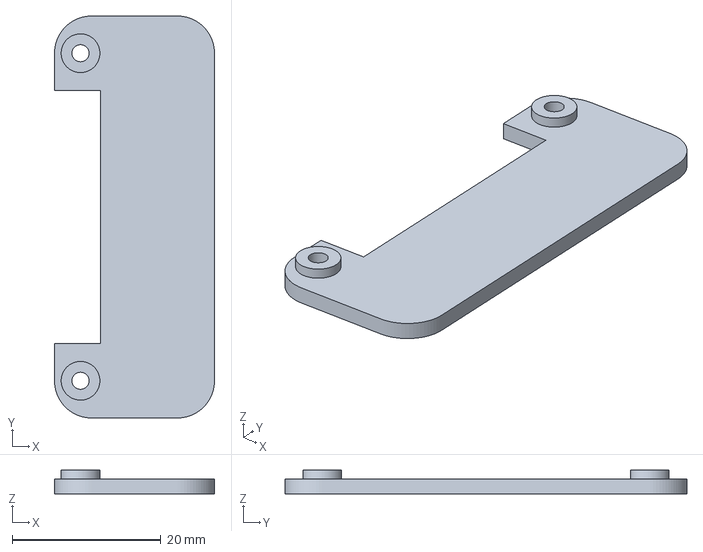
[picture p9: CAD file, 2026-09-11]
cad/3mf/UpperMouthBase.3mf
21.5 x 54.0 x 3.20 mm

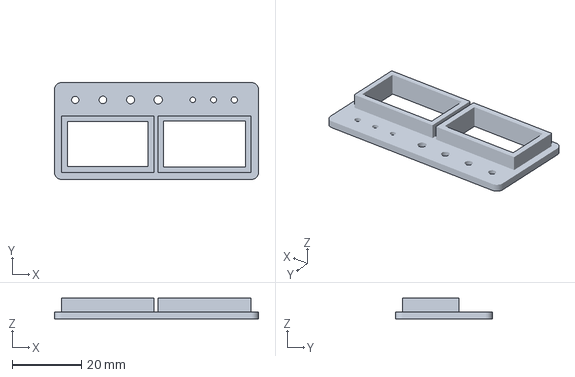
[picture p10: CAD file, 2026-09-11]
cad/3mf/ClearanceCoupon.3mf
59.0 x 28.0 x 6.00 mm

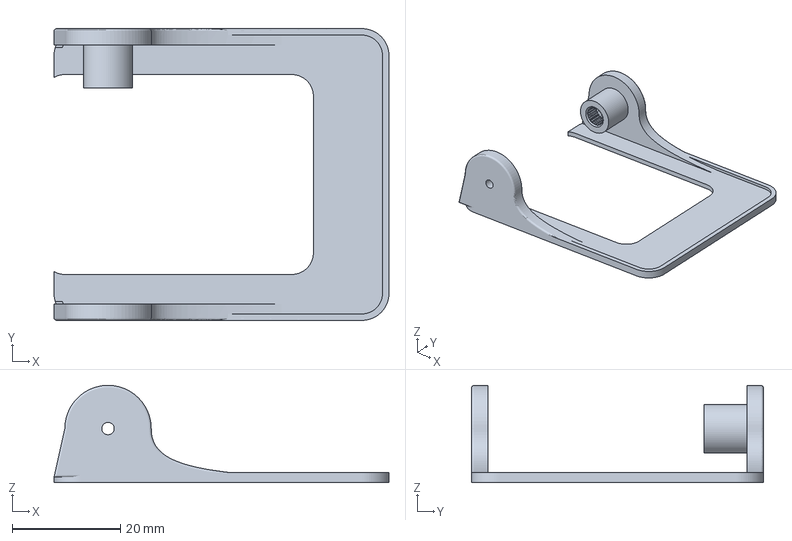
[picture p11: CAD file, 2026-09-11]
cad/3mf/Jaw.3mf
62.0 x 54.0 x 18.0 mm

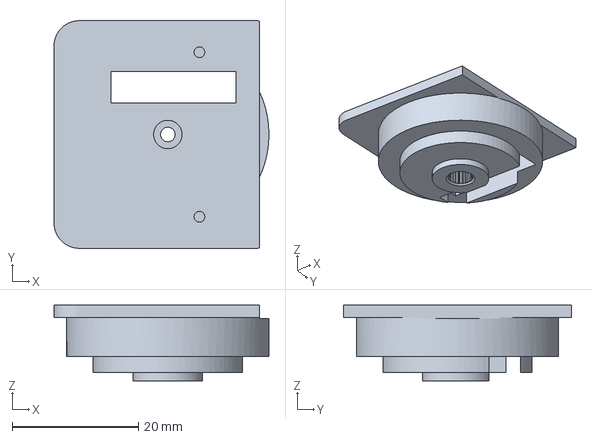
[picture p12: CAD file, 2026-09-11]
cad/3mf/NeckCarrier.3mf
34.0 x 36.0 x 12.0 mm

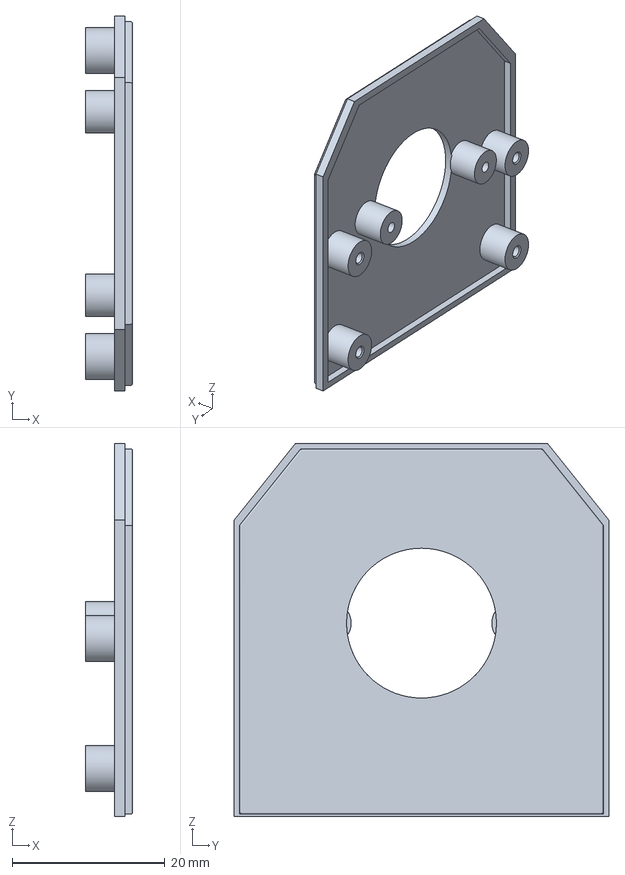
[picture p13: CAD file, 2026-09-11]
cad/3mf/FacePanel.3mf
6.20 x 49.0 x 48.8 mm

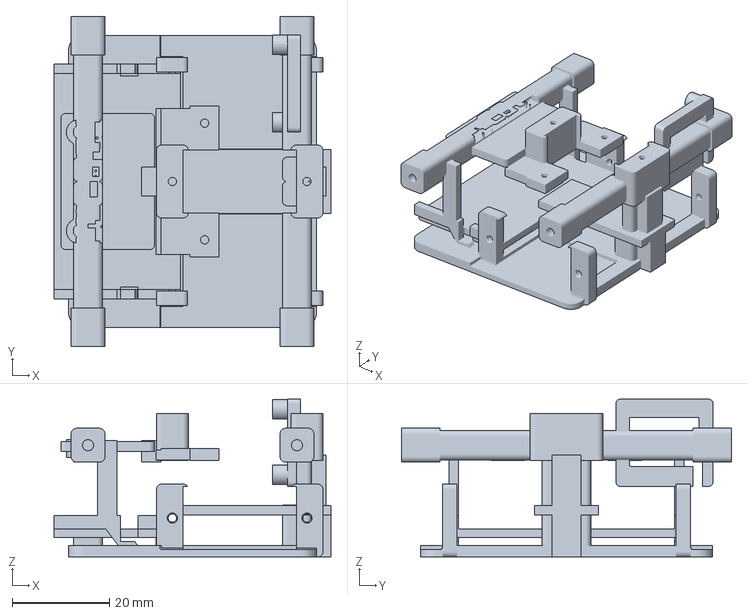
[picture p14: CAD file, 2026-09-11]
cad/3mf/Chassis.3mf
57.0 x 68.0 x 32.5 mm

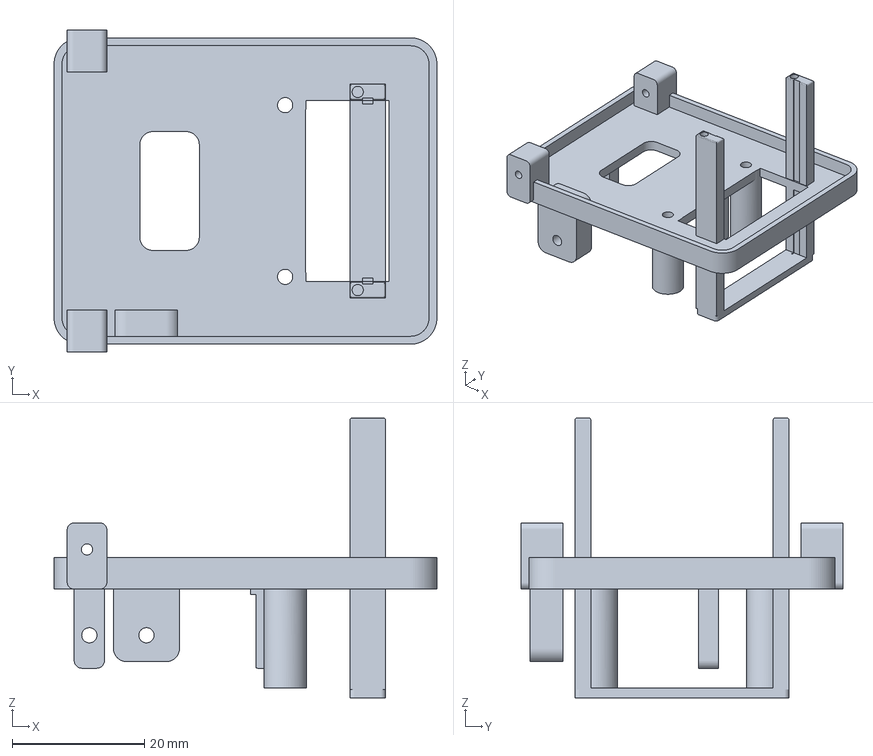
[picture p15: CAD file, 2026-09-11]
cad/3mf/HeadFrame.3mf
58.0 x 48.8 x 42.4 mm

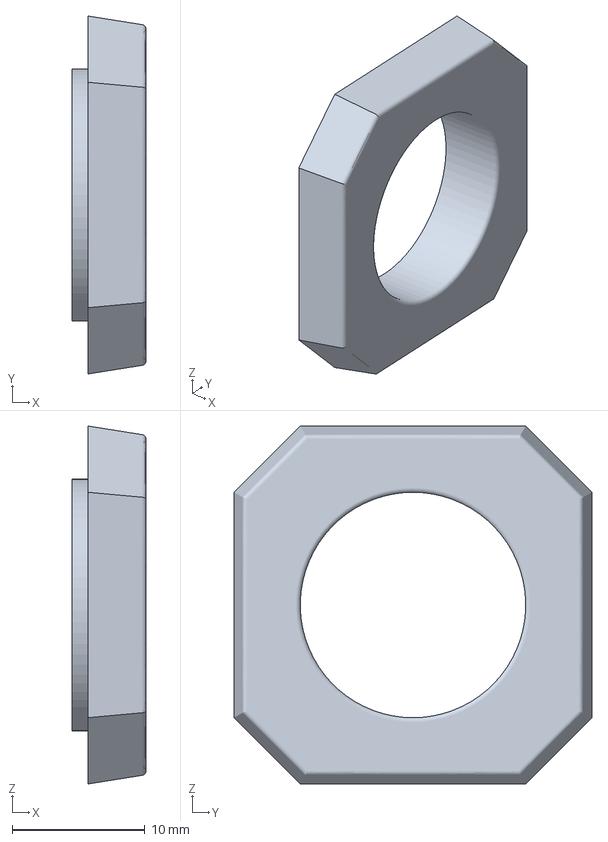
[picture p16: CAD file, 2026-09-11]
cad/3mf/CameraRing.3mf
5.60 x 27.0 x 27.0 mm

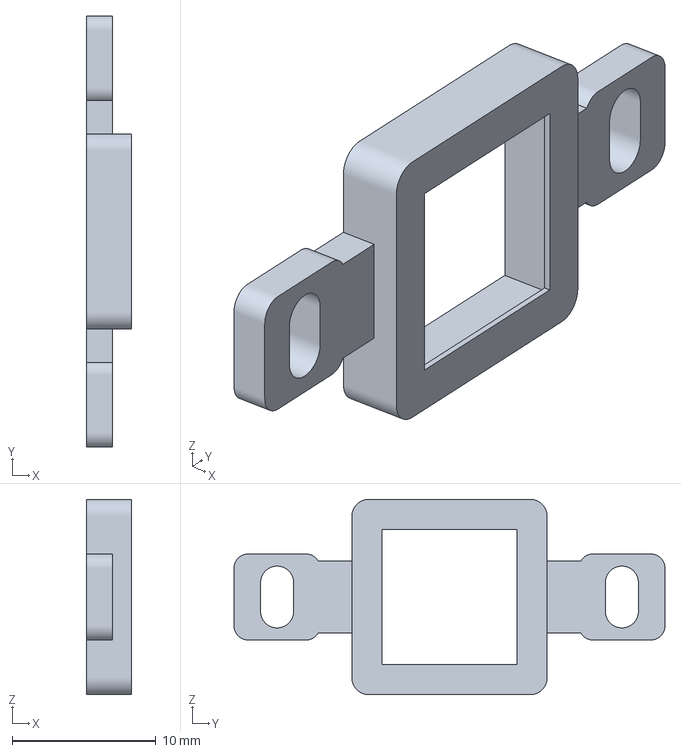
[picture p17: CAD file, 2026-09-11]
cad/3mf/CameraCradle.3mf
3.10 x 30.0 x 13.6 mm

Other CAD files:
cad/3mf/LegFootRight.3mf
cad/3mf/BodyShellRight.3mf
cad/3mf/CameraBoardClamp.3mf
cad/3mf/BodyShellLeft.3mf
cad/3mf/FixedNeckSupport.3mf
cad/stl/BodyShellLeft.stl
cad/stl/BodyShellRight.stl
cad/stl/CameraBoardClamp.stl
cad/stl/CameraCradle.stl
cad/stl/CameraRing.stl
cad/stl/Chassis.stl
cad/stl/ClearanceCoupon.stl
cad/stl/FacePanel.stl
cad/stl/FixedNeckSupport.stl
cad/stl/HeadFrame.stl
cad/stl/HeadHood.stl
cad/stl/Jaw.stl
cad/stl/LegFootLeft.stl
cad/stl/LegFootRight.stl
cad/stl/NeckCarrier.stl
cad/stl/SplineFitCoupon.stl
cad/stl/UpperMouthBase.stl

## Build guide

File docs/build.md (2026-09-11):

# Build and validate

Run commands from the repository root. Python 3.10 or newer is required for the source; the publication checks were run with Python 3.12. The numerical tools need NumPy and trimesh. FreeCAD and NVIDIA's simulation tools are separate installations.

## Numerical checks without CAD or Isaac

```sh
python -m venv .venv
```

Activate the environment (`.venv\Scripts\Activate.ps1` in PowerShell, or `source .venv/bin/activate` on Linux/macOS), then:

```sh
python -m pip install -r requirements-dev.txt
python -m unittest discover -s simulation/tests -v
python -m unittest discover -s scripts/tests -v
```

The simulation tests create their own small fixtures. They check millimetre-to-metre conversion, inertias, articulation topology, mass balance and stale evidence rejection. They require neither a generated robot nor Isaac and do not establish that the robot will walk.

## Local CAD rebuild

The source was developed against FreeCAD 1.1's Python modules (`FreeCAD`, `Part`, `MeshPart` and `PartDesign`). Use a Python interpreter supplied by or configured for that installation; installing a package named `FreeCAD` into an ordinary environment is not an equivalent setup. Set `$fcPython` in PowerShell to that interpreter's executable path and verify it before building:

```powershell
& $fcPython -c "import FreeCAD, Part, MeshPart, PartDesign; print(FreeCAD.Version())"
python scripts/fetch_reference_inputs.py
python scripts/fetch_reference_inputs.py --verify
& $fcPython src/build_cad.py
& $fcPython src/audit_cad.py
& $fcPython src/check_assembly_paths.py
& $fcPython src/check_detail_interfaces.py
& $fcPython src/check_display_geometry.py
& $fcPython src/check_harness_routes.py
```

On Linux, use the same script paths with your configured FreeCAD Python interpreter. FreeCAD distribution layouts differ; the import check above is the prerequisite, not an assumed installation path.

Edit parameters and construction logic in `src/build_cad.py`, `src/body_r04.py`, `src/head_r04.py`, `src/electronics_r04.py`, `src/direct_mount_r07.py` and `src/upper_mouth_r08.py`. The module suffixes record their introduction; the active `design_revision` is R08. The parameter spreadsheet in the resulting document is a record, not a live parametric rebuild interface.

The builder writes `build/local/cad/MicroDuckling_R01.FCStd`, `build/local/cad/assembly.json`, part meshes and a print-only STEP. `R01` is a legacy filename; check `design_revision` for the actual revision. The full scene includes locally downloaded electronics. These full assemblies, input files and detailed hardware meshes are intentionally Git-ignored. Published geometry is curated separately; see [license scope](licensing.md). A successful local build does not authorize publishing every generated file.

All CAD checks and simulation tools use the same `build/local/` root. To use a different generated-output directory, set `MICRODUCKLING_BUILD_ROOT` before invoking them. Keep it separate from the repository's public files; in-repository output roots are limited to `build/` or `work/`. The manufacturer input cache remains in the repository's `references/components_r02/`.

To validate and package the 17 current print/coupon meshes locally, then generate a separate public review export:

```powershell
python scripts/package_printables.py --source build/local
& $fcPython scripts/export_public_cad.py --source build/local --output build/public-check
```

The first command writes geometry-only 3MFs under `build/local/exports/3mf_review/`; the second filters approved geometry into `build/public-check/`. Inspect that export before deliberately replacing the published `cad/` files. Omit `--output` only when intentionally updating those public files.

## Derive local simulation assets

NumPy must also be importable in the FreeCAD Python environment for the derivation step:

```powershell
& $fcPython -c "import numpy; print(numpy.__version__)"
& $fcPython simulation/derive_manifest.py
python simulation/export_urdf.py
python simulation/validate_assets.py
python simulation/assess_balance.py
```

The derivation reopens the saved FreeCAD assembly, accounts for every non-coupon part, derives link-local meshes, and combines component masses and inertias. It writes local generated files under `build/local/cad/` and `build/local/simulation/`. These outputs are omitted from the public source repository because full link meshes contain vendor geometry. Regenerate them locally; do not bypass the hash checks or replace missing assets with unrelated meshes.

To derive a separate public browser review asset, combining local mass/inertia data with the original public tread hulls:

```sh
python simulation/browser/derive_asset.py build/local/cad/manifest.json build/browser-check/robot-physics.json --mesh-dir cad/meshes
```

Use the matching tread directory from a separate public export when reviewing changed CAD. The browser generator records both tread hashes, preserves mass independently of collider shape, and embeds the recommended convex/600 Hz/16-iteration settings. See [contact evidence and regeneration](browser-contact-physics.md) before intentionally replacing the checked-in browser asset.

The next step requires a compatible Isaac installation and an actual import/smoke run. See [simulation](simulation.md).

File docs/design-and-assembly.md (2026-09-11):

# Assembly and fit development

R08 is a four-servo prototype with two rigid leg/rocker-foot prints, a faceted torso, neck yaw, an independent face and a shell-mounted upper-mouth base and a moving lower jaw. Physical assembly, printed strength and powered operation remain unverified. Start with the [measurement worksheet](hardware-measurements.md) and [BOM](bom.md).

## Datums and motion

Coordinates are X forward, Y left, Z up, in millimetres. Hip axes are at global Z = 38 mm; the neck pivot is at Z = 80 mm. Nominal joint travel is hips ±12°, neck ±45°, jaw 0–12°. These are modeled ranges, not calibrated servo endpoints. Check the direct socket seating and sweep the printed parts with the complete cable/connector envelopes.

The torso is 76 × 78 × 37 mm. The head is 52 mm wide across the face, 64 mm deep and 52 mm high. The shared 5 V regulator, IMU and battery sit in the torso; ESP32-CAM, the separate flex camera and mouth servo occupy the head. The nominal assembly envelope is 76 × 112 × 136 mm.

## Assembly fasteners

Use nominal M2 screws for the printed-part connections. Where nut pockets are modeled, fit the corresponding captive M2 nuts; the passive jaw pivot uses its M2 locknut. The remaining printed pilots need qualification with the selected 2 mm thread-forming fastener. Common CAD holes are 2.30 mm passing clearance and 1.70 mm pilot diameter (0.85 mm radius). Check the actual print, screw type, engagement depth and repeated-assembly strength before accepting these dimensions. Do not assume every connection has a nut pocket.

The four center screws retaining the direct servo sockets must match the actual servo output threads. Their nominal 2 mm visual diameter is not an M2 thread specification. See [fastener measurements](hardware-measurements.md) for the different locations and grip stacks.

## Provisional assembly order

1. Measure all servo output splines and retaining screws. Print the clearance and spline coupons; the default 20T/4.8 mm major/4.30 mm root profile is provisional. Qualify the selected fasteners in representative-depth pilots.
2. Fit the bare chassis and torso servo cases. Install the vertical D24V50F5 before the battery, IMU and removable neck support obstruct its inside-facing screws. Its modeled insertion lowers from above, then seats 2 mm forward.
3. Wire the single regulator to separate servo and camera power branches with common ground; follow the [electronics allocation](electronics.md). The PCA9685 and second regulator are absent in R08.
4. Thread the restraint tape through the chassis slots before adding the insulating pad and battery. Qualify its overlap and release path without fastening directly to the pouch. Fit the body IMU and check screw-tip clearance.
5. Seat the leg and neck carrier sockets directly on the matching servo splines. Retain them with the matching central screws, checking actual grip, seating and blind-hole depth. Check the neck support, actual thrust shim and carrier stack for weight support without preload. There are no horn arms or horn-to-print screws.
6. Prepare the loose hood before fitting the face or electronics. Load its two upper-mouth M2 nuts through the open front, seat the separate upper-mouth base on its hood registers and install its two flush M2×8 countersunk screws from below while the jaw is absent. The base has no attachment to the face. Fit the face independently: its four M2 screws enter from the rear, so their straight access paths require the hood to remain off the populated head frame. See [R08 mount geometry and nut loading](r08-upper-mouth-design.md).
7. Preassemble the mouth servo with the jaw while the head frame and passive pivot are absent. Raise the servo through the central jaw opening, then move it 4 mm along its shaft axis into the jaw socket. Seat the center retaining screw with the required engagement. The checked reverse path withdraws the servo 4 mm toward negative Y before lowering it through the jaw. Raise the complete jaw/servo module into the bare head frame, then seat it 0.5 mm inward along the shaft axis. This reverses the checked module withdrawal path of 0.5 mm outward followed by 40 mm down. Keep the passive pivot and neck carrier off until the module is seated. Fit the vertical ESP32-CAM, removable clamp and camera cradle once access permits.
8. After installing the preassembled jaw/servo module, fit the passive pivot, retaining free motion and nominal endplay. Do not assume the rigid one-piece jaw can be slid sideways onto an already installed mouth servo and passive pivot. Connect the head to the neck, route the actual loom and align the camera without stressing its flex. Check full combined travel before fitting the prepared hood/face/upper-mouth module and body shells.

This sequence reflects sampled nominal insertion paths. Those checks compare components to named bare frames; they do not prove every installed-neighbor, nut or screwdriver path. Use the actual hardware to confirm the sequence.

## Printing and materials

Public STLs and 3MFs use millimetres. The 3MFs contain geometry only. Choose printer-specific orientation and supports; qualify thin walls, leg layer strength, small pilots and the curved sole finish. The source uses 1.3 mm torso walls, approximately 1.2 mm hood walls, 3.6 mm leg uprights and 2.2 mm foot material. CAD plastic mass assumes solid material at 1.24 g/cm³, so sliced and weighed masses will differ.

Tread, restraint tape and the insulating pad are separate material envelopes. Their material, adhesion, compression, friction and retention need tests. Do not scale purchased geometry to make a print fit; update the relevant dimensions and regenerate.

See [R08 changes](r08-upper-mouth-design.md), the historical [R05 refinement](r05-assembly-refinement.md), [engineering review](engineering-review.md) and [simulation](simulation.md) for evidence and remaining work.

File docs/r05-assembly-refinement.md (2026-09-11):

# R05 assembly refinement

Historical revision; see [R08 changes](r08-upper-mouth-design.md) for the current build.

R05 retains the compact R04 head, torso proportions and four MG90S joints. It addresses assembly defects identified in the saved nominal CAD. It remains an engineering prototype without physical fit, powered operation or walking validation.

| Area | R05 change | Remaining qualification |
|---|---|---|
| Controller clearance | Relieves the left shell's internal locating lip near the terminal and PCB edge; nominal gap increases from 0.388 mm to about 1.23 mm. The 1.3 mm outer wall stays unchanged. | Actual fitted connector envelope, print tolerances and shell flex. |
| Rear access | Extends a previously incomplete cutter through the rear wall and lip. Nominal opening is 14 × 10 mm; an 8 × 4 mm straight probe passes through both halves. | Actual plug insertion, disconnect and strain relief. |
| Battery restraint | Repositions 3.6 mm slots away from a supporting pedestal; models 3 mm tape with a 7 mm lap and a 22 × 42 × 0.7 mm insulating pad. | Tape material, overlap fastening, compression, pack fit and removable retention. |
| Head wiring | Replaces routes through the mouth mechanism with three indicative 0.84 mm corridors toward the ESP32 header region; extends the carrier notch. | Full conductor count, actual insulation, plugs, bend radius and neck-yaw service loop. |
| Camera flex | Routes from the FFC region toward the sensor while clearing the nominal SD cage, tray and cradle. | Actual flex length, latch seating and motion without crease or tension. |

The nominal mass estimate is **257.28 g**. Neutral global COM is approximately **(0.19, 0.57, 57.23) mm**, with the hip axis at X = 0. The overall envelope remains **76 × 112 × 136 mm**. There are 14 robot prints and two fit coupons. These values include estimated purchased hardware and full-density printed solids; they are not measurements of a built robot.

Public viewer geometry omits four detailed vendor-derived board models. The mass metadata still describes the full intended assembly. Displayed geometry volume must not be used to recompute that complete mass estimate.

Read the [engineering review](engineering-review.md) for exactly what was checked and the [assembly guide](design-and-assembly.md) before using the nominal hardware dimensions.

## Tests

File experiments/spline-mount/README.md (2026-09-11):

# Direct output-shaft fit experiments

The current design retains the [R07 direct mounts](../../docs/r07-direct-mount-design.md), with female spline sockets built directly into both legs, the neck carrier and the lower jaw. No projecting horn arms are installed. Its default 20T/4.8 mm major/4.30 mm root profile is provisional until measured against the actual servo batch. The public spline coupon tests that integrated interface; the separate experiment below also explores replaceable hex inserts as a possible future refinement.

A confirmed matching metal female insert remains an option if printed teeth cannot carry repeated loads. It is not a required component of the current model. The direct printed sockets have no verified cyclic-torque rating. Retain the four-servo arrangement, neck thrust support and jaw's passive pivot.

## What is known about the servo

- TowerPro's current [MG90S page](https://towerpro.com.tw/product/mg90s-3/) lists a 22.8×12.2×28.5 mm body and 1.8 kgf·cm stall torque at 4.8 V. It does not specify the output spline dimensions and notes shaft/gear material changes. The model name alone is not a dimensional interface drawing.
- [Adafruit technical support](https://forums.adafruit.com/viewtopic.php?t=95879) identified its 2016 MG90S as 20 teeth with 4.8 mm outer diameter. Its [current product 1143](https://www.adafruit.com/product/1143) is an MG90D, also listed as 20 splines; it was revised in 2018. This does not verify another supplier's MG90S.
- A different seller's own [MG90S listing](https://createlabz.store/products/micro-servo-motor-mg905-metal-gear-180-degrees) specifies 21T/4.86 mm. This is evidence of conflicting supplier interfaces, not a verified match to the user's unit.
- The supplied Amazon URL lacks a product ASIN, so it has not established the actual variant. No purchase or nominal fit choice has been made from it.

The example's root diameter, tooth flank shape, engagement depth and screw clearance are explicitly illustrative. An exact socket requires tooth count, major diameter, minor/root diameter, usable tooth height, tooth-tip/root widths or a square-on macro image with scale, shaft shoulder/crown clearance, and the retaining screw's measured diameter/pitch/head/available engagement. Also measure the actual seated supplied horn's axial stack and inspect several servos from the pack for consistency.

## Historical horn interfaces and optional insert study

The table records the pre-R07 horn interfaces that informed the original insert study. It is historical, not current assembly guidance. Dimensions were authored CAD assumptions, not measurements of hardware:

| Interface | Historical R06 model | Optional insert study |
| --- | --- | --- |
| Servo output | Smooth Ø4.8×4 mm cylinder in `servo_y`; no teeth; Ø8.5×2.4 mm illustrative horn hub | Replace the abstract fit assumption with a measured insert; retain the servo case and joint-axis datums |
| Hips | Ø10 mm central leg clearance, 3.6 mm upright, open radial arm slots; inner leg face at global Y±42.6 mm after widening | A local reinforced boss with keyed insert pocket; fill the old arm slots, preserve foot and pivot positions, extend the boss inward only by the measured shaft-to-leg stack |
| Neck | Ø12 mm central carrier passage, underside horn screw positions at 7 and 11 mm radius, separate thrust shoulder/shim | Keyed central insert carrier; retain thrust shoulder/shim so the spline does not become the head's axial bearing |
| Lower bill | 3 mm driven cheek with Ø4.6 mm center opening and arm screws at 7 and 11 mm radius; separate passive pivot | Locally reinforced keyed socket at the existing pivot; retain passive support and remove arm-only holes after fit validation |

Source: public `src/build_cad.py` (`servo_y`, `horn_y`, leg and neck blocks) and `src/head_r04.py` (jaw attachment). That historical horn and shaft stack was explicitly assumed. A direct mount must not be sized by simply subtracting the old horn thickness.

Proposed replaceable insert: nominal 9 mm across-flats hex exterior, about 3.7 mm axial height, and a central through screw. A matching printed carrier pocket starts at 9.2 mm across flats for a coupon test, with at least 2 mm of surrounding material and a positive axial shoulder. The hex transfers torque; the central screw provides retention. A metal insert's **actual** outer profile, flange and screw access replace these illustrative dimensions. Do not substitute a common 25T standard-size servo insert for an unverified 20T/21T micro spline.

## Optional replaceable-insert experiment

Run [build_coupon.py](build_coupon.py) with FreeCAD's Python. `--config measured-spline.json` accepts the same keys as `illustrative-20t.json`. It creates five socket cups with radial allowances 0/0.03/0.06/0.09/0.12 mm, identified by 1–5 through-dots on a side tab, plus one plain hex insert. All six STLs, a combined STEP and an editable native FCStd stay under the ignored `build/spline-fit/` directory and are clearly named `UNVERIFIED_*`. The radial tooth profile is an original trapezoidal approximation, not an involute or a claimed vendor spline standard.

Print the socket opening upward so its axis is vertical and the fine tooth shape lies in XY. The example 20T/4.8 mm diameter gives 0.754 mm circumferential pitch; its 30% tip fraction is about 0.226 mm. That feature is smaller than a typical 0.4 mm nozzle's 0.45 mm extrusion width. This is a geometric comparison and a reason to inspect the slicer preview and use finer XY capability; reducing layer height alone does not solve it. [Prusa's design guide](https://help.prusa3d.com/article/modeling-with-3d-printing-in-mind_164135), [layer-height guidance](https://help.prusa3d.com/article/layers-and-perimeters_1748)

At a 2.3 mm effective radius, 0.09 N·m torque corresponds to about 39 N tangential force, and the manufacturer's 1.8 kgf·cm stall figure converts to about 0.177 N·m or 77 N. These are simple force estimates, not a tooth stress calculation or a rated continuous operating load. Unequal tooth contact, wear, layer orientation and the small retention stack make a matched metal insert the more prudent starting point for repeated hip loading. Coupon fit alone does not prove strength.

First confirm tooth count and profile, then check gentle seating and backlash with the servo unpowered. Do not use the retaining screw to force a mismatched socket onto the shaft. Evaluate torque retention separately with a representative insert/carrier assembly and loads below the measured safe operating limit; a brief fit check cannot establish a fatigue rating.

Validation completed: all six exported meshes are closed; all native parts are single valid solids and reopen correctly. A 21-tooth/4.86 mm algorithm variation also builds, and four invalid parameter combinations are rejected. No physical fit or torque test has been performed. R07 uses integrated direct sockets in the actual assembly; these six optional insert-study parts are separate from the canonical print set. Neither the integrated profile nor this experiment establishes physical fit to the unknown servo batch.

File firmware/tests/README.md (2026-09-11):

# Host checks

From the repository root on Linux, with a C11 compiler such as GCC installed:

```sh
sh firmware/tests/run-host.sh
```

The script works from any working directory, uses `cc` by default, and accepts a compiler executable through `CC`. It compiles with `-Wall -Wextra -Werror`, runs both test cases, and removes its own temporary executable. No ESP-IDF installation, downloaded headers, board or network connection is required.

On Windows, the same check can run through WSL with GCC installed. This PowerShell command was run successfully in the development checkout:

```powershell
wsl -e sh -lc 'cd /mnt/e/Dev/freecad/MicroDuckling && sh firmware/tests/run-host.sh'
```

Change the `/mnt/e/...` path to the location of your clone. A native Windows target build is not implied by this WSL command.

The tests compile the real `microduckling_io.c` against original, minimal declarations and fake peripheral calls in `stubs/` and `test_io.c`. These files are not copied or vendored ESP-IDF SDK headers. They check pin separation, reserved PSRAM pins, the explicit PWM bank/frequency, IMU bus selection, zero-duty startup, calibration and angle rejection, pulse conversion, and stopping configured outputs after initialization or write failures. The duty model stages a value separately from applying it, and injects failures in both `ledc_set_duty()` and `ledc_update_duty()`. The combined fade-service-dependent helper is deliberately absent from the test interface.

This check does **not** establish ESP-IDF API/ABI compatibility, real PWM timing, camera/PSRAM operation, reset voltage levels, or safe servo power behavior. An ESP-IDF target build and the hardware checks in [electronics.md](../../docs/electronics.md) remain separate requirements.

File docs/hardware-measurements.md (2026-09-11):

# Hardware measurement worksheet

**No physical measurements are recorded yet.** Leave result cells blank until measured. CAD values below are hypotheses. Label servos **L**, **R**, **N**, **M** for left/right hip, neck and mouth; keep each servo's supplied center screw identified with its servo. Stock horns can serve as measurement references but are not installed in R08.

| Identification | Record |
|---|---|
| Date, operator, source revision | |
| Supplier, SKU, PCB revision, batch and photographs | |
| Caliper resolution and zero check; scale resolution | |
| Printer, material, orientation, layer height | |
| Power supply/pack, instruments and test conditions | |

Use millimetres and grams. For servos define **A** as the flat base opposite the shaft, **B** as the short case end nearest the shaft, and **C** as a marked long side. Heights run from A toward the shaft. Distinguish the rectangular case, mounting ears, fixed crown, spline and fully seated direct socket. Measure unpowered external geometry; do not force an unknown screw or open the gearcase to identify it.

## Servo geometry

| Measurement | CAD assumption, not measured | L | R | N | M |
|---|---:|---|---|---|---|
| Case length × width | 22.8 × 12.4 | | | | |
| A to rectangular case top / highest fixed crown | 25.8 / 28.5 | | | | |
| A to spline tip | 32.5 | | | | |
| Shaft center from B / C | 6.2 / 6.2 | | | | |
| Ear outer span / selected hole pitch | 32.1 / 27.7 | | | | |
| A to ear underside / ear thickness | 18.5 / 2.8 | | | | |
| Hole/slot diameter and actual center coordinates | Ø2.2 modeled | | | | |
| Both crown lobes: outline, offsets and heights | approximate | | | | |
| Lead exit, cable size and plugged connector envelope | unknown | | | | |
| Installed mass, including stated lead length | 13.4 g | | | | |

Hole pitch is not the ear's total span. Locate shaft centers from measured tangents and shaft radii consistently. Photograph the crown and output spline beside a scale in the same plane; include a square-on macro view for tooth counting.

## Direct spline, screw and thrust stack

The actual printed leg, neck carrier and jaw sockets now use a configurable 20T profile with 4.8 mm major and 4.30 mm root diameters. **These are unverified assumptions, not a measured MG90S standard.** Use the spline coupon before printing or loading a complete interface. Record several servos from the same pack; the model name does not establish interchangeable output shafts.

| Measurement | L | R | N | M |
|---|---|---|---|---|
| Tooth count, major diameter and root diameter | | | | |
| Tooth tip/root widths and flank shape; macro photograph reference | | | | |
| Usable spline height and shoulder/crown outline | | | | |
| Socket's actual printed allowance and seated depth | | | | |
| A to seated socket outer face and screw-head top | | | | |
| Center screw diameter/pitch, under-head length and usable engagement | | | | |
| Backlash, axial play, radial rocking and full sweep clearance | | | | |
| Repeat assembly and representative load/wear result | | | | |

Do not use the retaining screw to force an incorrect tooth profile onto the shaft. Confirm the socket seats on its intended shoulder and does not bottom on the shaft tip; check screw engagement and blind depth separately. For the neck, record support top → actual thrust shim → carrier shoulder and verify support without axial preload. The nominal shim is 0.20 mm; a gap alone does not carry weight. See [direct-spline interface parameters retained from R07](r07-direct-mount-design.md) and the [spline experiment](../experiments/spline-mount/README.md).

| Fastener location | Nominal intent | Actual thread / head / length | Grip stack / engagement / tip clearance | Result |
|---|---|---|---|---|
| Hip ears | 4 × M2×6, printed pilots | | | |
| Mouth ears | 2 × M2×8 with nuts | | | |
| Passive jaw pivot | M2×12 with locknut; 0.2 mm nominal endplay | | | |
| Servo regulator / IMU mounts | M2×6 | | | |
| Camera clamp / cradle | M2×6 | | | |
| Upper-mouth base to hood | 2 × M2×8 countersunk, captive M2 nuts; 90° head reference | | | |
| Hood, face, shells and neck attachments | M2; check source length and pilot or captive-nut location | | | |
| Four direct-socket center retaining screws | Vendor-specific thread; 2 mm CAD envelope is not an M2 specification | | | |

Printed-part assembly fasteners are nominal M2. Common CAD passing holes are Ø2.30 mm, and common printed pilots are Ø1.70 mm (0.85 mm radius). Qualify the pilots with the selected 2 mm thread-forming fastener, printer and material; record cracking, stripping and repeated assembly in a representative-depth sample. The clearance coupon supplies Ø2.1/2.2/2.3/2.4 mm passing holes and Ø1.6/1.7/1.8 mm pilot trials. Captive M2 nuts apply only at modeled pockets; retain the passive jaw pivot's M2 locknut. No nut is assumed behind a plain printed pilot.

Nominal cylindrical CAD screws do not model threads. The four servo-output center screws are vendor-specific despite their 2 mm visual envelope; measure their thread rather than substituting an M2 screw by appearance. For a straight stack, engagement is under-head length minus unthreaded grip length; include washers, recesses and gaps. Verify blind depth and tip clearance. The thin clearance coupon checks diameters, not thread retention: use a representative-depth pilot sample for stripping, cracking and repeated assembly tests.

## Electronics, camera and battery

| Component | Actual outline / thickness | Top and bottom fitted envelope, including plugs | Retention / clearance | Installed mass |
|---|---|---|---|---|
| Adafruit LSM6DS3TR-C 4503 | | | | |
| Pololu D24V50F5 | | | | |
| ESP32-CAM and fitted headers | | | | |
| OV2640 carrier, lens and flex | | | | |
| 2S pack, discharge and balance plugs | | | | |

Use the [BOM](bom.md) only as a reference column. Measure camera carrier size, lens projection/optical center, flex width/length/orientation, latch access and usable cradle adjustment. The provisional camera carrier and barrel are 10 mm and 8 mm envelopes. Do not load the ribbon to achieve lens alignment.

## Assembly and electrical qualification

| Check | Observation / measurement | Status |
|---|---|---|
| Servo saddles seat on ears without distorting cases; direct sockets fully seat | | |
| Full direct-socket and printed-part sweeps: hips ±12°, neck ±45°, jaw 0–12° | | |
| All screw, nut, driver and component insertion paths in assembly order | | |
| Loose hood/face module closes; face screws accessible with module removed | | |
| Upper-mouth registers seat, captive nuts load and countersunk heads sit flush; jaw gap remains free | | |
| Board insulation, solder projections and release space for every plug | | |
| Battery pad and restraint fit; pack removable without pulling leads | | |
| Rear access, wire gauge, connectors, strain relief and neck service loop | | |
| Camera flex stays clear throughout actual head/jaw motion | | |
| Each servo neutral, sign and safe pulse/angle endpoints | | |
| Loaded lag, backlash, current, rail voltage and temperature over time | | |
| Simultaneous servo movement with camera/Wi-Fi and shell closed | | |
| Battery monitoring, undervoltage response, watchdog and power shutdown | | |
| Weighed link masses/COM estimates, printed strength and tread friction | | |

Keep timestamped raw measurements and conditions. Stall torque is not a continuous loaded rating. Start powered tests with reduced motion and support for the mechanism; this worksheet does not qualify a finished robot. See [assembly](design-and-assembly.md) and [simulation calibration](simulation.md).

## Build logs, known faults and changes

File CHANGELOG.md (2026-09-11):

# Changelog

## 0.1.0-cad-preview — 2026-09-11

First public development snapshot of the R05 design.

- Original parametric CAD source, a public mechanical FreeCAD model and a printed-part STEP.
- Fourteen robot print parts and two fit coupons in STL and 3MF.
- Local CAD viewer with assembly, exploded and parts views, part downloads and four joint controls.
- Original mascot, actual CAD renders, contribution guidance and a staged hardware/simulation roadmap.
- Local reference downloader with source hashes and explicit license boundaries.
- Automated file, mesh, viewer and simulation source checks.

This is a **prerelease for design review**. Physical fit, powered assembly, walking and Isaac runtime/training have not been demonstrated. The public preview omits four supplier board geometries; the complete intended physical assembly still requires those components. See the [engineering review](docs/engineering-review.md) before printing or purchasing parts.

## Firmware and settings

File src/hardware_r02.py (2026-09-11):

"""Purchased electronics geometry in millimetres; local PCB XY, bottom Z=0.

Adafruit XY outlines, holes, pads and package placements come directly from
the saved manufacturer Eagle files. Unlisted Z dimensions and generic fitted
header details are explicit modeling assumptions, not measured vendor CAD.
Pololu collision geometry is the unmodified vendor STEP. Its view groups
partition the original faces, with heuristic colors only.

Every public function returns shape, components[{name,shape,color}],
pcb_dimensions_mm, mount_holes[[x,y,diameter]], notes, and source_files.
Components contain exactly the displayed geometry; no invisible substitute
box replaces the returned collision solid/compound. A camera on its flex is
intentionally separate from esp32cam(). This module does not write files.
"""
from pathlib import Path
import math
import xml.etree.ElementTree as ET
import FreeCAD as App
import Part

REF = Path(__file__).resolve().parents[1] / "references/components_r02"
V = App.Vector
BLUE, BLACK, GOLD, SILVER = "#155a83", "#24262a", "#cfa956", "#b8bec4"
TAN, WHITE, GREEN = "#9b8964", "#e6e7de", "#47af61"


def _box(x, y, z, dx, dy, dz):
    return Part.makeBox(dx, dy, dz, V(x, y, z))


def _cyl(x, y, z, radius, height):
    return Part.makeCylinder(radius, height, V(x, y, z))


def _compound(shapes):
    return Part.makeCompound(shapes)


def _item(items, name, shape, color):
    if shape.isNull() or not shape.isValid():
        raise RuntimeError("Invalid hardware geometry: " + name)
    items.append(dict(name=name, shape=shape, color=color))


def _result(items, pcb, holes, notes, sources, shape=None, **metadata):
    shape = shape if shape is not None else _compound([x["shape"] for x in items])
    if shape.isNull() or not shape.isValid() or not shape.Solids:
        raise RuntimeError("Invalid complete hardware geometry")
    return dict(shape=shape, components=items, pcb_dimensions_mm=pcb,
                mount_holes=holes, notes=notes, source_files=list(sources), **metadata)


def _arc_wire(node, offset):
    x1,y1,x2,y2 = [float(node.get(k)) for k in ("x1","y1","x2","y2")]
    start,end = V(x1+offset[0],y1+offset[1],0),V(x2+offset[0],y2+offset[1],0)
    angle = math.radians(float(node.get("curve",0)))
    if abs(angle) < 1e-10:
        return Part.makeLine(start,end)
    delta=end-start
    center=(start+end)*.5+V(-delta.y,delta.x,0)*(1/(2*math.tan(angle/2)))
    arm=start-center;c,s=math.cos(angle/2),math.sin(angle/2)
    mid=center+V(arm.x*c-arm.y*s,arm.x*s+arm.y*c,0)
    return Part.Arc(start,mid,end).toShape()


def _placement(shape, element, offset):
    shape=shape.copy();rotation=element.get("rot","R0")
    if "M" in rotation:
        shape=shape.mirror(V(),V(1,0,0))
    shape.rotate(V(),V(0,0,1),float(rotation.split("R")[-1]))
    shape.translate(V(float(element.get("x"))+offset[0],float(element.get("y"))+offset[1],0))
    return shape


def _point(element, x, y, offset):
    rotation=element.get("rot","R0");angle=math.radians(float(rotation.split("R")[-1]))
    if "M" in rotation:x=-x
    return [float(element.get("x"))+offset[0]+x*math.cos(angle)-y*math.sin(angle),
            float(element.get("y"))+offset[1]+x*math.sin(angle)+y*math.cos(angle)]
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

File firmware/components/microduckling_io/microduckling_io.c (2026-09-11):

// SPDX-License-Identifier: Apache-2.0
#include "microduckling_io.h"
#include <math.h>
#include <stdbool.h>
#include <string.h>
#include "driver/ledc.h"
#include "sdkconfig.h"

#if !CONFIG_IDF_TARGET_ESP32
#error "This pin map and high-speed LEDC bank require classic ESP32, not ESP32-S3/C3."
#endif
#if !CONFIG_SPIRAM
#error "Enable PSRAM for the selected ESP32-CAM configuration."
#endif
#if !CONFIG_SCCB_HARDWARE_I2C_PORT0 || !CONFIG_SCCB_HARDWARE_I2C_DRIVER_NEW
#error "Select camera SCCB I2C0 and the new I2C driver; I2C1 is reserved for the IMU."
#endif
#if !CONFIG_ESP_CONSOLE_NONE || !CONFIG_BOOTLOADER_LOG_LEVEL_NONE
#error "Disable the UART console and bootloader logs before reusing GPIO1/3 for the IMU."
#endif

#define SERVO_MODE LEDC_HIGH_SPEED_MODE
#define SERVO_TIMER LEDC_TIMER_0
#define SERVO_HZ 50U
#define SERVO_STEPS 65536U
#define HIP_LIMIT 0.20943951023931953f
#define NECK_LIMIT 0.7853981633974483f
static const int pins[MD_SERVO_COUNT] = {
    MD_LEFT_HIP_GPIO, MD_RIGHT_HIP_GPIO, MD_NECK_GPIO, MD_JAW_GPIO
};
static const float lower[MD_SERVO_COUNT] = {-HIP_LIMIT, -HIP_LIMIT, -NECK_LIMIT, 0};
static const float upper[MD_SERVO_COUNT] = { HIP_LIMIT,  HIP_LIMIT,  NECK_LIMIT, HIP_LIMIT};
static md_servo_calibration_t cal[MD_SERVO_COUNT];
static unsigned configured_channels;
static bool ready;

camera_config_t md_camera_config(void)
{
    return (camera_config_t) {
        .pin_pwdn = 32, .pin_reset = -1, .pin_xclk = 0,
        .pin_sccb_sda = 26, .pin_sccb_scl = 27,
        .pin_d0 = 5, .pin_d1 = 18, .pin_d2 = 19, .pin_d3 = 21,
        .pin_d4 = 36, .pin_d5 = 39, .pin_d6 = 34, .pin_d7 = 35,
        .pin_vsync = 25, .pin_href = 23, .pin_pclk = 22,
        .xclk_freq_hz = 20000000,
        .ledc_timer = LEDC_TIMER_0, .ledc_channel = LEDC_CHANNEL_0,
        .pixel_format = PIXFORMAT_JPEG, .frame_size = FRAMESIZE_QVGA,
        .jpeg_quality = 12, .fb_count = 1,
        .fb_location = CAMERA_FB_IN_PSRAM, .grab_mode = CAMERA_GRAB_WHEN_EMPTY,
    };
}

esp_err_t md_imu_bus_init(i2c_master_bus_handle_t *bus)
{
    if (!bus) return ESP_ERR_INVALID_ARG;
    const i2c_master_bus_config_t config = {
        .i2c_port = I2C_NUM_1, .sda_io_num = MD_IMU_SDA_GPIO,
        .scl_io_num = MD_IMU_SCL_GPIO, .clk_source = I2C_CLK_SRC_DEFAULT,
        .glitch_ignore_cnt = 7, .flags.enable_internal_pullup = false,
    };
    // Use the breakout's external pull-ups to 3.3 V. Sensor driver is separate.
    return i2c_new_master_bus(&config, bus);
}

esp_err_t md_servos_stop(void)
{
    esp_err_t result = ESP_OK;
    for (unsigned i = 0; i < configured_channels; ++i) {
        const esp_err_t err = ledc_stop(SERVO_MODE, (ledc_channel_t)i, 0);
        if (err != ESP_OK) result = err;
    }
    return result;
}

esp_err_t md_servos_init(const md_servo_calibration_t calibration[MD_SERVO_COUNT])
{
    if (ready || configured_channels) return ESP_ERR_INVALID_STATE;
    if (!calibration) return ESP_ERR_INVALID_ARG;
    for (unsigned i = 0; i < MD_SERVO_COUNT; ++i) {
        const md_servo_calibration_t *c = &calibration[i];
        if (!isfinite(c->neutral_us) || !isfinite(c->us_per_rad) || c->us_per_rad == 0 ||
            c->min_pulse_us < 500 || c->max_pulse_us > 2500 || c->min_pulse_us >= c->max_pulse_us)
            return ESP_ERR_INVALID_ARG;
        const float a = c->neutral_us + lower[i] * c->us_per_rad;
        const float b = c->neutral_us + upper[i] * c->us_per_rad;
        if (!isfinite(a) || !isfinite(b) || fminf(a, b) < c->min_pulse_us || fmaxf(a, b) > c->max_pulse_us)
            return ESP_ERR_INVALID_ARG;
    }
    const ledc_timer_config_t timer = {
        .speed_mode = SERVO_MODE, .duty_resolution = LEDC_TIMER_16_BIT,
        .timer_num = SERVO_TIMER, .freq_hz = SERVO_HZ, .clk_cfg = LEDC_USE_APB_CLK,
    };
    esp_err_t err = ledc_timer_config(&timer);
    if (err != ESP_OK) return err;
    for (unsigned i = 0; i < MD_SERVO_COUNT; ++i) {
        const ledc_channel_config_t channel = {
            .gpio_num = pins[i], .speed_mode = SERVO_MODE, .channel = (ledc_channel_t)i,
            .intr_type = LEDC_INTR_DISABLE, .timer_sel = SERVO_TIMER, .duty = 0, .hpoint = 0,
        };
        err = ledc_channel_config(&channel);
        if (err != ESP_OK) { md_servos_stop(); return err; }
        configured_channels++;
    }
    memcpy(cal, calibration, sizeof(cal));
    ready = true;
    return ESP_OK;
}

esp_err_t md_servos_write(const float radians[MD_SERVO_COUNT])
{
    if (!ready) return ESP_ERR_INVALID_STATE;
    if (!radians) return ESP_ERR_INVALID_ARG;
    uint32_t duties[MD_SERVO_COUNT];
    // Validate the complete command before writing any channel.
    for (unsigned i = 0; i < MD_SERVO_COUNT; ++i) {
        if (!isfinite(radians[i]) || radians[i] < lower[i] || radians[i] > upper[i])
            return ESP_ERR_INVALID_ARG;
        const float us = cal[i].neutral_us + radians[i] * cal[i].us_per_rad;
        if (!isfinite(us) || us < cal[i].min_pulse_us || us > cal[i].max_pulse_us)
            return ESP_ERR_INVALID_ARG;
        duties[i] = (uint32_t)lroundf(us * (SERVO_STEPS * SERVO_HZ / 1000000.0f));
    }
    for (unsigned i = 0; i < MD_SERVO_COUNT; ++i) {
        // This API has one owning control task. The combined thread-safe IDF
        // helper requires the fade service, which this component does not use.
        esp_err_t err = ledc_set_duty(SERVO_MODE, (ledc_channel_t)i, duties[i]);
        if (err != ESP_OK) { md_servos_stop(); return err; }
        err = ledc_update_duty(SERVO_MODE, (ledc_channel_t)i);
        if (err != ESP_OK) { md_servos_stop(); return err; }
    }
    return ESP_OK;
}

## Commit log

2026-09-11 Publish R05 CAD prototype and community project foundation
    [BodyShellLeft.3mf, BodyShellLeft.stl, BodyShellRight.3mf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]
2026-09-11 Declare graph dependency required by print mesh validation
2026-09-11 Restore electronics, refine assembly controls and add physics experiments
    [ServoController.json]
2026-09-11 Refine upper bill, direct servo wiring and physics training
    [BodyShellLeft.3mf, BodyShellLeft.stl, BodyShellRight.3mf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]
2026-09-11 Integrate direct servo mounts and add simulation tuning controls
    [BodyShellLeft.3mf, BodyShellRight.3mf, CameraBoardClamp.3mf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]
2026-09-11 Mount upper mouth beneath head shell with aligned lips
    [BodyShellLeft.3mf, BodyShellRight.3mf, CameraBoardClamp.3mf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]

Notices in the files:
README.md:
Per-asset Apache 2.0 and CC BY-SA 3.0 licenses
